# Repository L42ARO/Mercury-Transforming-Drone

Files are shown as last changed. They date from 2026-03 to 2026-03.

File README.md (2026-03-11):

# MERCURY - TRANSFORMING DRONE
<!-- Hardware / Platform -->







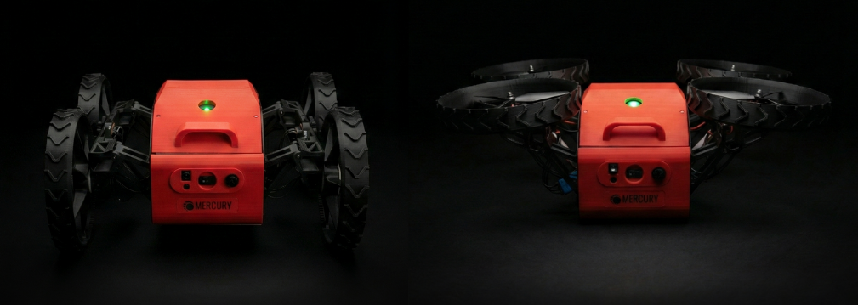
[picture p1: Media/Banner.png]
Mercury Banner





## Quick Index

- [Demo](#demo)
- [Features](#features)
- [Folder Structure](#folder-structure)
- [Software Setup](#software-setup)

## Demo

Mercury Demo (https://youtu.be/DZhdSxqXiKo)

## Features

<table width="100%">
  <tr>
    <td width="50%" align="center"><b>Inner Payload Bay (1 kg)</b></td>
    <td width="50%" align="center"><b>Simple Transformation Mechanism</b></td>
  </tr>
  <tr>
    <td width="50%" align="center">Inner Payload Bay</td>
    <td width="50%" align="center">Simple Transformation Mechanism</td>
  </tr>
</table>

<table width="100%">
  <tr>
    <td width="50%" align="center"><b>RGB + Depth + Thermal Cameras</b></td>
    <td width="50%" align="center"><b>Ardupilot + GPS</b></td>
  </tr>
  <tr>
    <td width="50%" align="center">RGB + Depth + Thermal Cameras</td>
    <td width="50%" align="center">Ardupilot + GPS</td>
  </tr>
</table>

<table width="100%">
  <tr>
    <td width="50%" align="center"><b>Wheel + Prop Guard</b></td>
    <td width="50%" align="center"><b>Mobile App</b></td>
  </tr>
  <tr>
    <td width="50%" align="center">Wheel + Prop Guard</td>
    <td width="50%" align="center">Mobile App</td>
  </tr>
</table>

## Folder Structure
- **STL Files:** all the required stl files for the drone assembly
- **Autonomy Software:** all the required software for the drone autonomy
- **PCB Files:** all the gerber files for the drone PCBs

## Software Setup

To use the software as it is, upload the Autonomy Software folder to a Raspberry Pi 5, using your preferred SCP method. For beginners we recommend [WinSCP](https://winscp.net/eng/download.php).

Inside the folder in the raspberry pi create a virtual environment and install the dependencies.

```bash
python3 -m venv venv
source venv/bin/activate
pip install -r requirements.txt
```

You must run both the Mavproxy Bridge to interface with the flight controller as well as the main software powering the rest of the robot. For that run in two separate temrinals the scripts:

```bash
start_mavproxy.sh
```
```bash
run.sh
```
In the terminal you should see the IP addres to be able to control the robot, if you're connected to the same network just copy paste that on your browser.

If you would like to be able to control it from different networks and at long distances we recommend you setup [Tailscale](https://tailscale.com/) on your devices.

For more convenience you can setup these scripts to run automatically on startup, and then use other scripts like `restarter.sh` or `killer.sh` to manage them.

## 🧑‍💻 Official Codebase Core Contributors and Maintainers

<table>
  <tr>
    <td align="center">
      <a href="https://x.com/L42ARO">
        
      </a>
      <br />
      <sub><b>Alvaro L</b></sub>
    </td>
    <td align="center">
      <a href="https://x.com/pericleshimself">
        
      </a>
      <br />
      <sub><b>Connor Raymer</b></sub>
    </td>
  </tr>
</table>



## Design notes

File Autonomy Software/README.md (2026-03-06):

# Mercury Delivery 🤖🧺🗺️

This repo is for TeleOperating delivery operations for Mercury

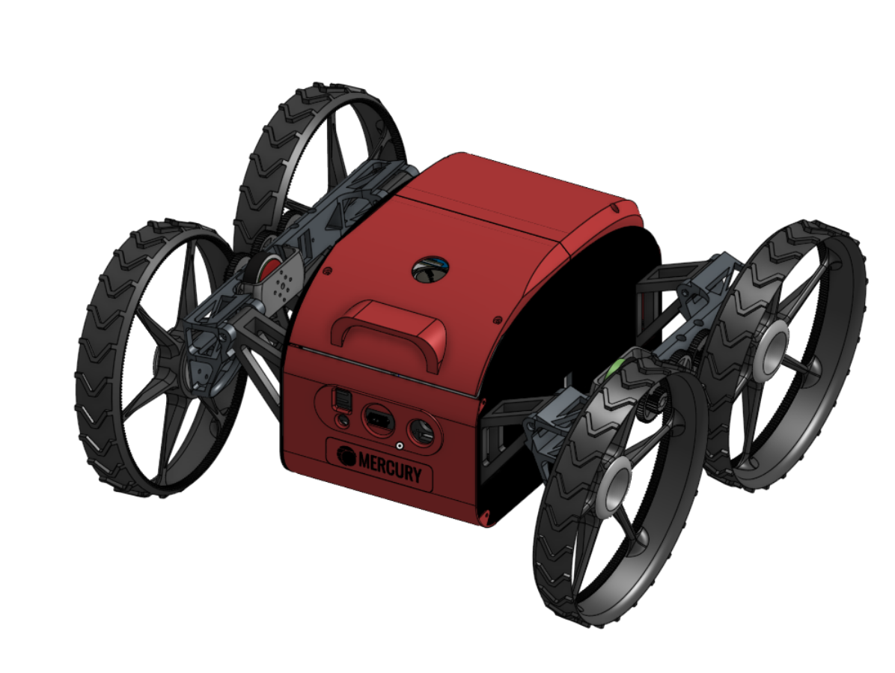
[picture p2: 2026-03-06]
Media/CAD.png

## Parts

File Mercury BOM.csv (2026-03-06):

Hardware | Link | Units
120N Linear Actuator 1.2" | https://a.co/d/f1gvmVA | 2
8 inch propellers | https://a.co/d/bCJhVNM | 4
BLDC Motor (A2812 2812 900KV) | https://a.co/d/0YZLBnR | 4
Raspberry Pi 5 | https://a.co/d/0e89eMiw | 1
Mobile Data Dongle | https://a.co/d/clkxkL8 | 1
Lipo Battery (3S 2200mah) | https://a.co/d/04b29lgE | 2
Screws (3mm x 10mm) | ACE Hardware | 10
Screws (3mm x 30 mm) | ACE Hardware | 20
Screws (3mm x 50 mm) | ACE Hardware | 10
CF 30 cm x 30 cm (for frame) | https://a.co/d/0dzbtn5p | 2
8 awg cable | https://www.amazon.com/dp/B07B8N6751?ref_=ppx_hzod_title_dt_b_fed_asin_title_0_1 | 1
T Plug Pairs | https://www.amazon.com/dp/B01C8NWJ78?ref_=ppx_hzod_title_dt_b_fed_asin_title_0_0 | 2
XT60 Male & Female | https://www.amazon.com/dp/B0CMM1BBDQ?ref_=ppx_hzod_title_dt_b_fed_asin_title_0_0 | 1
IMU (MPU 9250) | https://www.amazon.com/dp/B01I1J0Z7Y?ref_=ppx_hzod_title_dt_b_fed_asin_title_0_1 | 2
TOF Camera | https://www.amazon.com/dp/B0BRB12W7Y?ref_=ppx_hzod_title_dt_b_fed_asin_title_0_0 | 1
ESP32S3 | https://a.co/d/0fMawJYb | 1
USB Webcam | https://www.amazon.com/640x480-Building-Arduino-Raspberry-Robotic/dp/B0CT35HQJ5 | 1
Buck Converter | https://www.amazon.com/sspa/click | 3
Radiolink R8XM | https://www.amazon.com/dp/B0BCPDLWXZ?ref_=ppx_hzod_title_dt_b_fed_asin_title_0_0 | 1
DRV8871 H Bridge | https://a.co/d/iBVBORv | 2
Cube + Flight Controller | https://a.co/d/19FUWXO | 1
SEQURE 4in1 ESC 70A | https://a.co/d/5X12oWn | 1
Custom PCBS | EasyEDA | 3
BLDC Motor 140kv (for driving) | https://a.co/d/iKZayiN | 2
Optical Flow MTF-01 | https://www.ewingaerospace.com/products/ewing-aerospace-h7-flight-controller-ndaa-compliant-and-blueuas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 | 1
Thermal Camera | https://a.co/d/dZ3TK0W | 1
Bidirectional ESC 50A (for driving) | https://a.co/d/00C138fG | 2

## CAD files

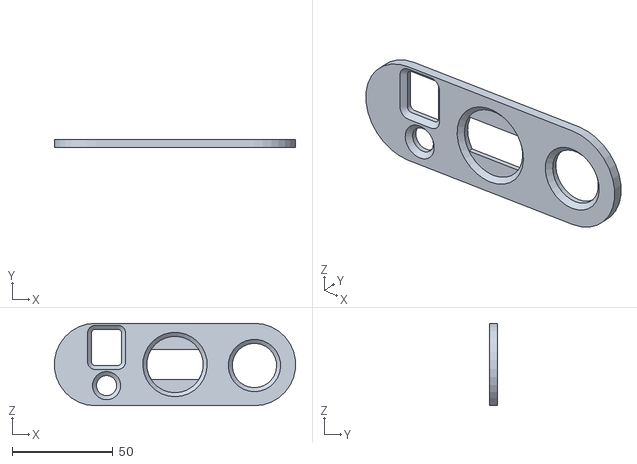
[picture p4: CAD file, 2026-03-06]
STL Files/Cover Out - Front Sensors.stl
119.8 x 4.00 x 41.0

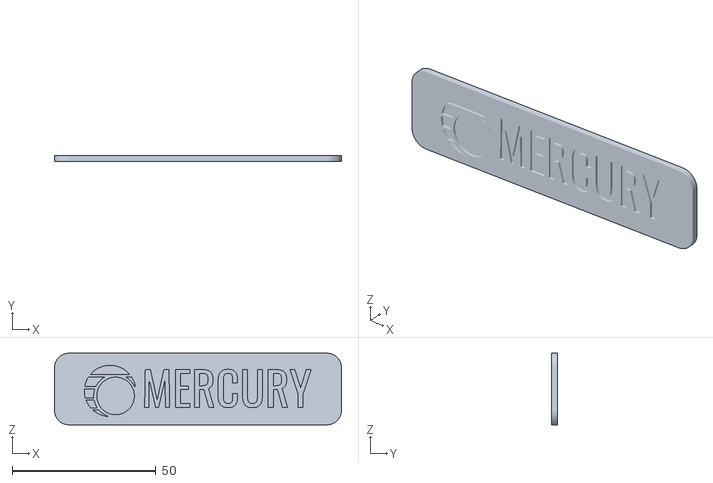
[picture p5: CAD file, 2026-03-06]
STL Files/Cover Out - Front Name.stl
100.0 x 2.00 x 25.0

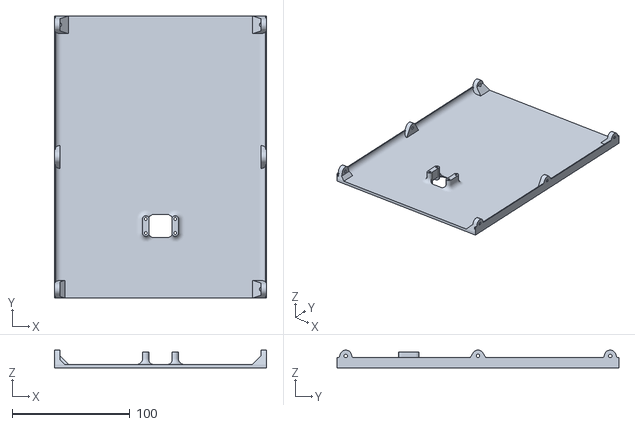
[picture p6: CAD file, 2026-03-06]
STL Files/Cover Out - Bottom.stl
180.8 x 240.0 x 15.1

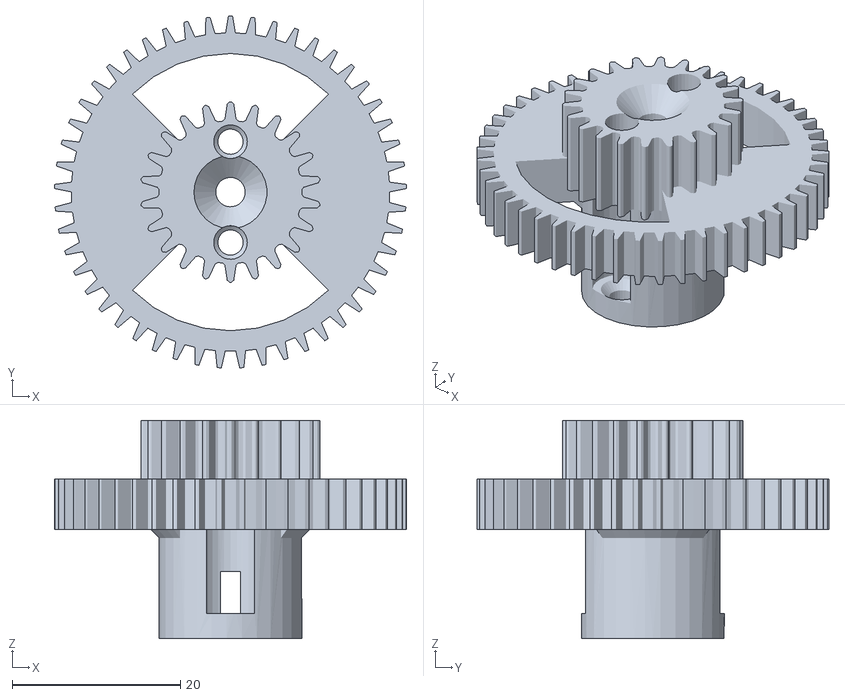
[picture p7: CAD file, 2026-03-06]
STL Files/Gear - Driving.stl
41.9 x 41.9 x 26.0

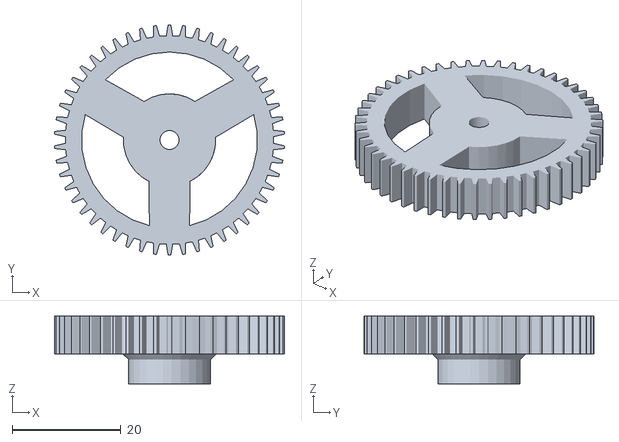
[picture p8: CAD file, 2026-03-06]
STL Files/Gear - Central.stl
42.3 x 42.4 x 12.5

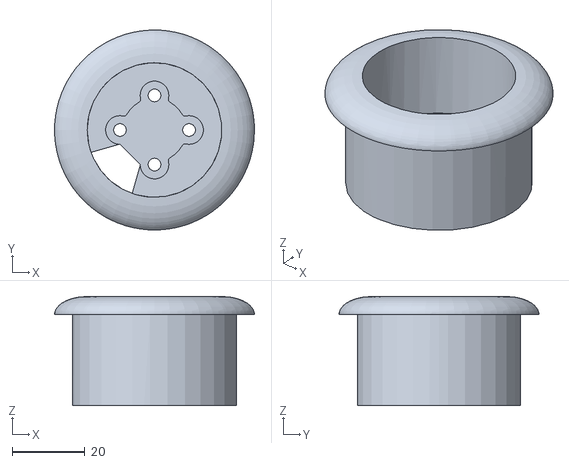
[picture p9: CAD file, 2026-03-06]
STL Files/Drone Motor Holder.stl
55.0 x 55.0 x 30.0

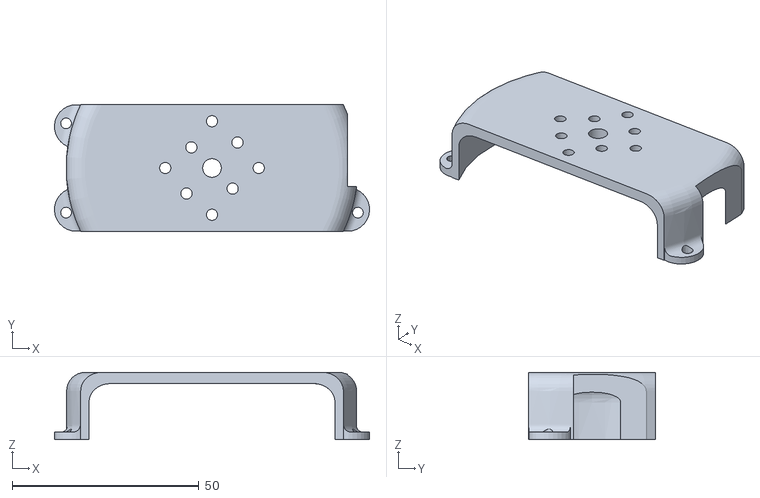
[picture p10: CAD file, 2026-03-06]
STL Files/BLDC Holder - Left.stl
84.2 x 33.9 x 18.0

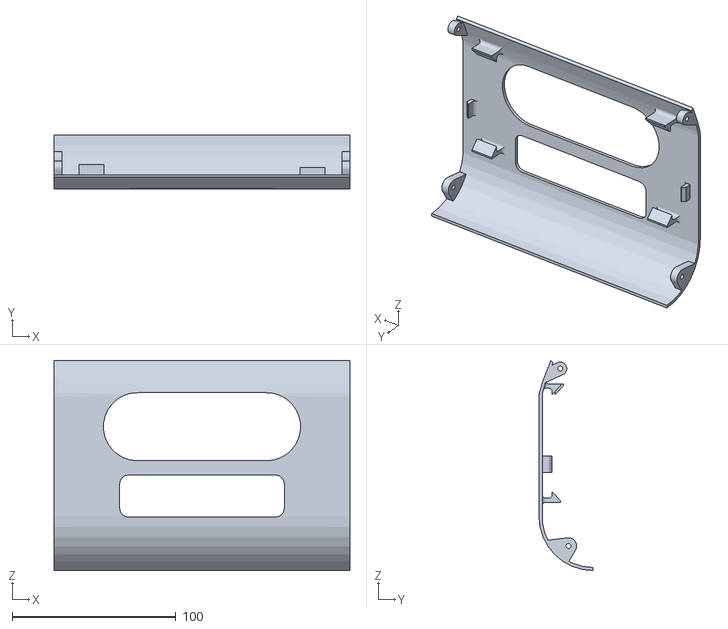
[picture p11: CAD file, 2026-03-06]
STL Files/Cover Out - Front.stl
180.8 x 33.0 x 128.3

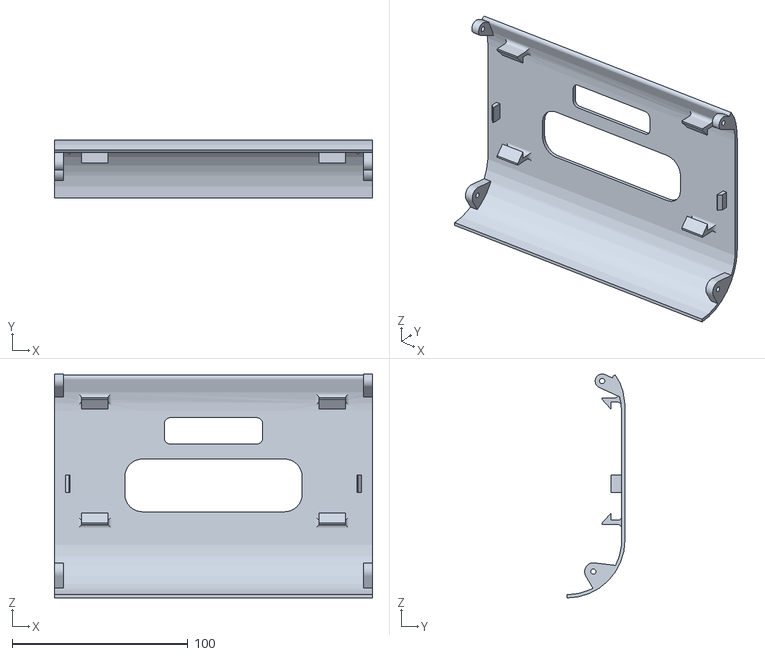
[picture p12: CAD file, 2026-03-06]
STL Files/Cover Out - Rear.stl
180.8 x 33.0 x 127.3

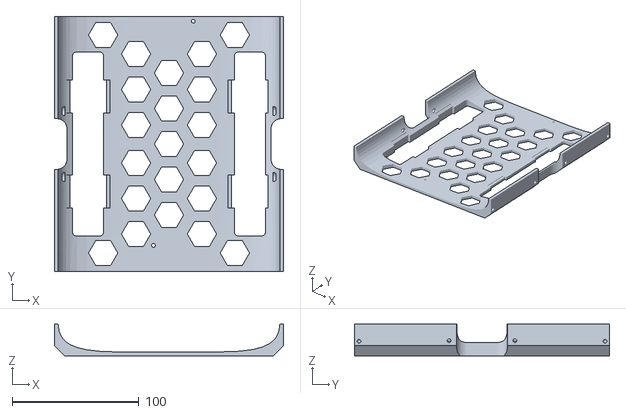
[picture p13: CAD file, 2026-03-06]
STL Files/CargoBay - Base.stl
180.8 x 201.2 x 25.0

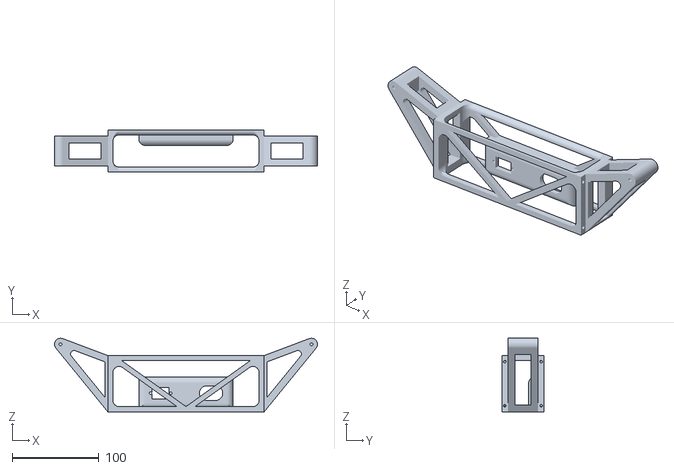
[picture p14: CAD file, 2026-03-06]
STL Files/ShoulderMount - Rear.stl
303.9 x 49.0 x 85.0

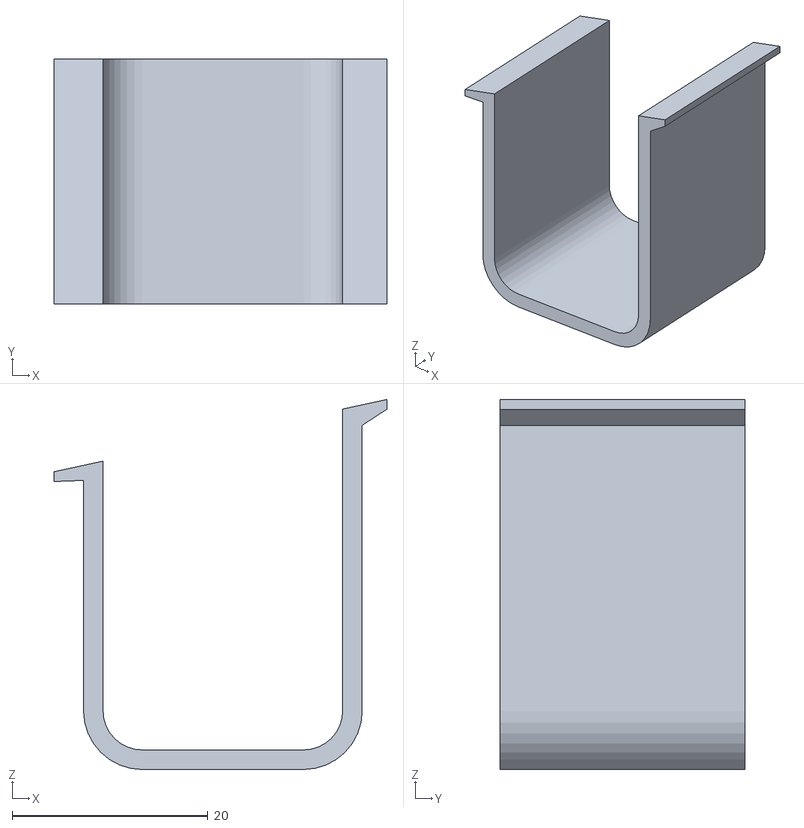
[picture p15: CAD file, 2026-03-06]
STL Files/CargoBay - Battery Holder 3.stl
34.0 x 25.0 x 37.8

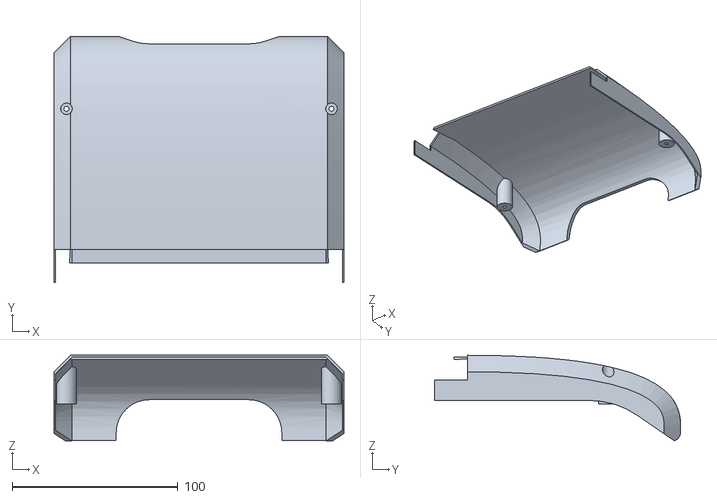
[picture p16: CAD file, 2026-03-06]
STL Files/Cover Out - Top Rear.stl
175.1 x 148.8 x 51.7

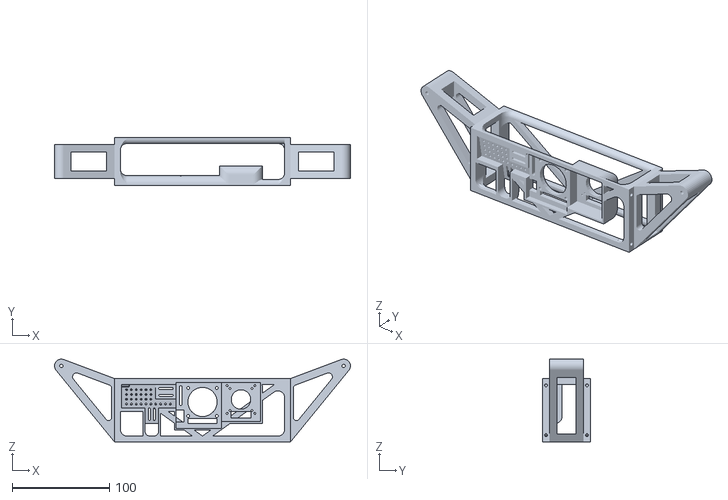
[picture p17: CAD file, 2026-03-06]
STL Files/ShoulderMount - Front.stl
303.9 x 49.0 x 85.0

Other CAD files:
STL Files/CargoBay - Battery Holder 4.stl
STL Files/BLDC Holder - Right.stl
STL Files/Cover Out - Top Front.stl
STL Files/Gear - Peripheral.stl
STL Files/CargoBay - Battery Holder 1.stl
STL Files/CargoBay - Battery Holder 2.stl
STL Files/CargoBay - Cover.stl
STL Files/Cover - Base.stl
STL Files/Linear Actuator Holder.stl

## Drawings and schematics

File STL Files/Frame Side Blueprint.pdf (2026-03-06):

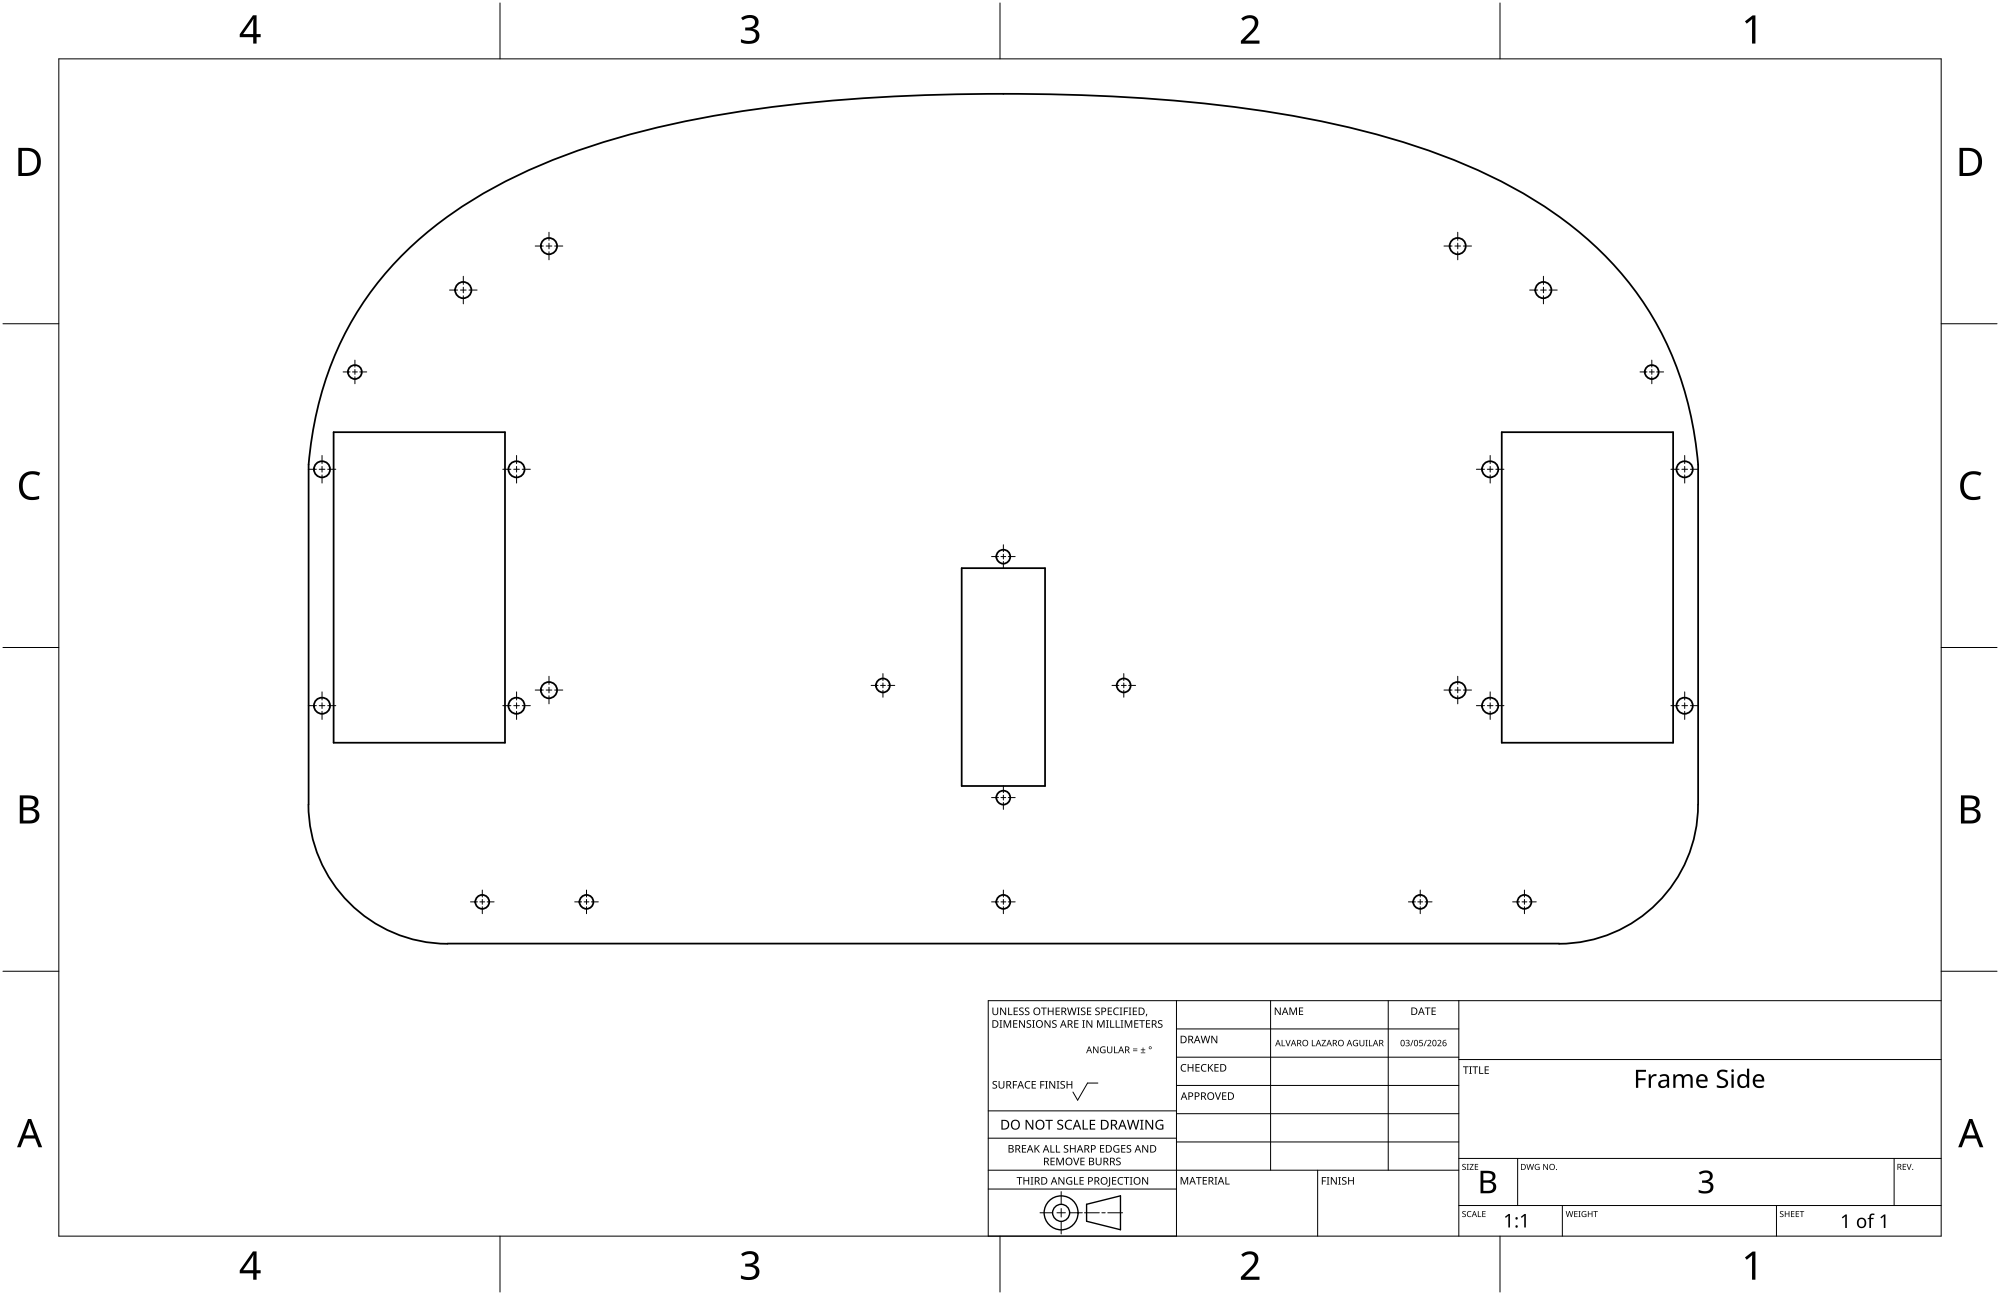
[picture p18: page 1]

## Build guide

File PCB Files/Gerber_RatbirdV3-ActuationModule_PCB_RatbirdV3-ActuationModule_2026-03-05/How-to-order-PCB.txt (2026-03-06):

How to Order PCB

Please refer to:
https://docs.easyeda.com/en/PCB/Order-PCB

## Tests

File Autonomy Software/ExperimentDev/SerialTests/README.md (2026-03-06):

# ACTUATION BOARD API

This document describes how to communicate with the ESP32-S3 controller from a Raspberry Pi using the **binary Serial 1 protocol** on `/dev/ttyAMA1`.
The API lets the Pi switch modes and drive the robot efficiently via framed byte packets (no strings).

---

## ⚙️ Serial setup

| Parameter | Value |
| --- | --- |
| Port | `/dev/ttyAMA1` |
| Baud rate | **115 200 bps** |
| Data format | 8 N 1 |
| TX / RX (Pi → ESP32) | ESP32 TX = D6, RX = D7 |
| Logic voltage | 3.3 V (direct UART) |

Python example:

```python
import serial
ser = serial.Serial('/dev/ttyAMA1', 115200, timeout=0.2)
```

---

## 🧱 Frame structure

Every packet (both directions) follows:

```
AA 55 <LEN> <CMD> <PAYLOAD…> <CHK>
```

| Field | Description |
| --- | --- |
| `AA 55` | Sync header |
| `<LEN>` | Payload + 1 byte for CMD |
| `<CMD>` | Command ID |
| `<PAYLOAD>` | Command-specific data |
| `<CHK>` | XOR of all bytes from `<LEN>` through last payload byte |

Example:
`AA 55 01 02 03` → `STOP_ALL` (len = 1, cmd = 0x02, chk = 0x03)

---

## 🧭 Command table (Pi → ESP32)

| CMD (HEX) | Name | Payload | Notes |
| --- | --- | --- | --- |
| `0x01` | **MODE_SET**  | `u8 mode` → 0 NONE  1 CAR  2 DRONE | Starts 10 s transform for CAR/DRONE |
| `0x02` | **STOP_ALL**  | – | Stops all motors immediately |
| `0x03` | **DRIVE_F** | `u8 pct (0-100)` | Forward (CAR mode only) |
| `0x04` | **DRIVE_B** | `u8 pct (0-100)` | Backward |
| `0x05` | **DRIVE_L** | `u8 pct (0-100)` | Left |
| `0x06` | **DRIVE_R** | `u8 pct (0-100)` | Right |
| `0x07` | **DRIVE_MIX** | `i8 left, i8 right` (-100..100) | Mixed differential drive |
| `0x08` | **TURNMODE**  | `u8 mode` → 0 SAME 1 TANK | Optional steering style |
| `0x09` | **DMAX_SET**  | `u16 delta_us (LE)` | Servo range 200-500 µs |
| `0x0A` | **STATUS_Q**  | – | Requests current status frame |

---

## 📡 Responses (ESP32 → Pi)

| Type | CMD ID | Payload | Meaning |
| --- | --- | --- | --- |
| **ACK** | `0x80` | `0x01` | OK |
| **ERR** | `0x81` | `u8 code` | 1 BadArg  2 BadMode  3 NotInCar  4 Unknown |
| **STATUS** | `0x82` | `mode u8 active u8 turn u8 dmax u16 reserved u8` | 6-byte status payload |

All responses use the same `AA 55 <LEN> <CMD> … <CHK>` format.

---

## ⏱ Timing guidelines

| Command type | Recommended wait before next |
| --- | --- |
| `MODE_SET` (CAR/DRONE) | ~ 10 s  (physical transform duration) |
| Drive commands (`F/B/L/R/MIX`) | Wait until motion finishes (typically 2-3 s) |
| `STOP_ALL` / `STATUS_Q` | 0.1 s |

---

## 🧪 Example Python usage

```python
import serial, struct, time
ser = serial.Serial('/dev/ttyAMA1', 115200, timeout=0.2)

def frame(cmd, payload=b''):
    body = bytes([len(payload)+1, cmd]) + payload
    chk = 0
    for x in body: chk ^= x
    return b'\xAA\x55' + body + bytes([chk])

def send(cmd, payload=b'', wait=0.0, label=''):
    print(f"➡️  {label or hex(cmd)}")
    ser.write(frame(cmd, payload))
    resp = ser.read(64)
    if resp: print("⬅️ ", resp.hex(' '))
    else:    print("⬅️  (no response)")
    time.sleep(wait)

# --- sample sequence ---
send(0x01, bytes([1]), 0.1, "MODE CAR")
print("waiting 10 s for transformation…")
time.sleep(10)

send(0x03, bytes([50]), 0.1, "DRIVE FORWARD 50%")
time.sleep(3)
send(0x02, b'', 0.1, "STOP_ALL")

payload = struct.pack('bb', -30, 60)
send(0x07, payload, 0.1, "DRIVE_MIX (-30,+60)")
time.sleep(2)
send(0x02, b'', 0.1, "STOP_ALL")

send(0x01, bytes([2]), 0.1, "MODE DRONE")
time.sleep(10)
send(0x0A, b'', 0.2, "STATUS_Q")
```

---

## 🪪 Quick reference (hex examples)

| Action | Frame |
| --- | --- |
| MODE CAR | `AA 55 02 01 01 03` |
| STOP_ALL | `AA 55 01 02 03` |
| DRIVE F 50% | `AA 55 02 03 32 31` |
| DRIVE MIX (-30,+60) | `AA 55 03 07 E2 3C 18` |
| STATUS_Q | `AA 55 01 0A 0B` |

---

## 🧰 Debugging tips

* Use `minicom` or `screen /dev/ttyAMA1 115200` to verify bytes.
* Every valid frame begins with `AA 55`.
* `0x80` ACK → success; `0x81` ERR → check payload for error code.
* If you get no response, ensure grounds are common and TX/RX aren’t swapped.

---

**Author:** Mercurius Robotics
**Purpose:** Efficient serial bridge for Pi ↔ ESP32 differential-drive controller.

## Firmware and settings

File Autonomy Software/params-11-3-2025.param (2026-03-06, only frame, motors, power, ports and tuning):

ATC_ANG_LIM_TC,1
ATC_ANG_PIT_P,4.5
ATC_ANG_RLL_P,4.5
ATC_ANG_YAW_P,4.5
ATC_ANGLE_BOOST,1
ATC_RAT_PIT_D,0.0036
ATC_RAT_PIT_D_FF,0
ATC_RAT_PIT_FF,0
ATC_RAT_PIT_FLTD,20
ATC_RAT_PIT_FLTE,0
ATC_RAT_PIT_FLTT,20
ATC_RAT_PIT_I,0.24
ATC_RAT_PIT_IMAX,0.5
ATC_RAT_PIT_P,0.22
ATC_RAT_PIT_PDMX,0
ATC_RAT_PIT_SMAX,0
ATC_RAT_RLL_D,0.0036
ATC_RAT_RLL_D_FF,0
ATC_RAT_RLL_FF,0
ATC_RAT_RLL_FLTD,20
ATC_RAT_RLL_FLTE,0
ATC_RAT_RLL_FLTT,20
ATC_RAT_RLL_I,0.24
ATC_RAT_RLL_IMAX,0.5
ATC_RAT_RLL_P,0.22
ATC_RAT_RLL_PDMX,0
ATC_RAT_RLL_SMAX,0
ATC_RAT_YAW_D,0
ATC_RAT_YAW_D_FF,0
ATC_RAT_YAW_FF,0
ATC_RAT_YAW_FLTD,20
ATC_RAT_YAW_FLTE,10
ATC_RAT_YAW_FLTT,10
ATC_RAT_YAW_I,0.24
ATC_RAT_YAW_IMAX,0.5
ATC_RAT_YAW_P,0.22
ATC_RAT_YAW_PDMX,0
ATC_RAT_YAW_SMAX,0
ATC_RATE_FF_ENAB,1
ATC_RATE_P_MAX,0
ATC_RATE_R_MAX,0
ATC_RATE_Y_MAX,0
BATT_AMP_OFFSET,0
BATT_AMP_PERVLT,52
BATT_ARM_MAH,0
BATT_ARM_VOLT,0
BATT_CAPACITY,2200
BATT_CRT_MAH,0
BATT_CRT_VOLT,0
BATT_CURR_PIN,11
BATT_FS_CRT_ACT,0
BATT_FS_LOW_ACT,0
BATT_FS_VOLTSRC,0
BATT_LOW_MAH,0
BATT_LOW_TIMER,10
BATT_LOW_VOLT,10.5
BATT_MONITOR,4
BATT_OPTIONS,0
BATT_SERIAL_NUM,-1
BATT_VLT_OFFSET,0
BATT_VOLT_MULT,11.2
BATT_VOLT_PIN,10
BATT2_MONITOR,0
BATT3_MONITOR,0
BATT4_MONITOR,0
BATT5_MONITOR,0
BATT6_MONITOR,0
BATT7_MONITOR,0
BATT8_MONITOR,0
BATT9_MONITOR,0
FLTMODE_CH,5
FLTMODE_GCSBLOCK,0
FLTMODE1,2
FLTMODE2,2
FLTMODE3,9
FLTMODE4,16
FLTMODE5,6
FLTMODE6,9
FRAME_CLASS,1
FRAME_TYPE,1
INS_GYRO_FILTER,20
INS_HNTCH_ENABLE,0
MOT_BAT_CURR_MAX,35
MOT_BAT_CURR_TC,5
MOT_BAT_IDX,0
MOT_BAT_VOLT_MAX,0
MOT_BAT_VOLT_MIN,0
MOT_BOOST_SCALE,0
MOT_HOVER_LEARN,2
MOT_OPTIONS,0
MOT_PWM_MAX,2000
MOT_PWM_MIN,1000
MOT_PWM_TYPE,6
MOT_SAFE_DISARM,0
MOT_SAFE_TIME,1
MOT_SLEW_DN_TIME,0
MOT_SLEW_UP_TIME,0
MOT_SPIN_ARM,0.1
MOT_SPIN_MAX,0.95
MOT_SPIN_MIN,0.15
MOT_SPOOL_TIM_DN,0
MOT_SPOOL_TIME,0.5
MOT_THST_EXPO,0.65
MOT_THST_HOVER,0.668889
MOT_YAW_HEADROOM,200
SERIAL0_BAUD,115
SERIAL0_PROTOCOL,2
SERIAL1_BAUD,115
SERIAL1_OPTIONS,8
SERIAL1_PROTOCOL,2
SERIAL2_BAUD,9
SERIAL2_OPTIONS,0
SERIAL2_PROTOCOL,23
SERIAL3_BAUD,115
SERIAL3_OPTIONS,1184
SERIAL3_PROTOCOL,1
SERIAL4_BAUD,57
SERIAL4_OPTIONS,0
SERIAL4_PROTOCOL,2
SERIAL5_BAUD,115
SERIAL5_OPTIONS,0
SERIAL5_PROTOCOL,16
SERIAL6_BAUD,9
SERIAL6_OPTIONS,0
SERIAL6_PROTOCOL,5
SERVO1_FUNCTION,34
SERVO1_MAX,2000
SERVO1_MIN,1000
SERVO1_REVERSED,0
SERVO1_TRIM,1000
SERVO2_FUNCTION,35
SERVO2_MAX,2000
SERVO2_MIN,1000
SERVO2_REVERSED,0
SERVO2_TRIM,1000
SERVO3_FUNCTION,36
SERVO3_MAX,2000
SERVO3_MIN,1000
SERVO3_REVERSED,0
SERVO3_TRIM,1000
SERVO4_FUNCTION,33
SERVO4_MAX,2000
SERVO4_MIN,1000
SERVO4_REVERSED,0
SERVO4_TRIM,1000
SERVO5_FUNCTION,0
SERVO5_MAX,1900
SERVO5_MIN,1100
SERVO5_REVERSED,0
SERVO5_TRIM,1500
SERVO6_FUNCTION,0
SERVO6_MAX,1900
SERVO6_MIN,1100
SERVO6_REVERSED,0
SERVO6_TRIM,1500
SERVO7_FUNCTION,0
SERVO7_MAX,1900
SERVO7_MIN,1100
SERVO7_REVERSED,0
SERVO7_TRIM,1500
SERVO8_FUNCTION,0
SERVO8_MAX,1900
SERVO8_MIN,1100
SERVO8_REVERSED,0
SERVO8_TRIM,1500
SERVO9_FUNCTION,120
SERVO9_MAX,1900
SERVO9_MIN,1100
SERVO9_REVERSED,0
SERVO9_TRIM,1500

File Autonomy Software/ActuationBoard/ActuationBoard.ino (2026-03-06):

// ================== Pins: TRANSFORMATION (H-bridge) ==================
// ================== Pins: TRANSFORMATION (H-bridge) ==================
#define ENA D10     // <— moved off D0 to free D0
#define IN1 D1
#define IN2 D2
#define IN3 D3
#define ENB D10     // (if ENA/ENB tie together in your board, keep both on D10 or split as needed)
#define IN4 39

// New: lock servo pin
#define LOCK_SERVO_PIN D0   // XIAO ESP32S3 D0 = GPIO1 (PWM-capable)


// ================== Pins: DRIVE SERVOS (DIFFERENTIAL) ==================
#define SERVO_LEFT_PIN  D9   // LEFT drive servo
#define SERVO_RIGHT_PIN D8   // RIGHT drive servo

// ================== LED ==================
#ifdef LED_BUILTIN
  #define LED_PIN LED_BUILTIN
#else
  #define LED_PIN 2
#endif
#define LED_ACTIVE_HIGH false

// ================== Timing ==================
const uint32_t CAR_RUN_MS   = 10000; // 10 s transform after MODE CAR
const uint32_t DRONE_RUN_MS = 10000; // 10 s transform after MODE DRONE
const uint32_t LED_DRONE_INTERVAL = 300; // blink while DRONE active

// ================== Serial1 (Raspberry Pi link) ==================
#define RX_PIN D7
#define TX_PIN D6
#define BAUD   115200

// ================== Includes ==================
#include "ModeController.h"
#include "DriveController.h"
#include "Serial1API.h"
#include "LockController.h"


// ================== Human CLI over USB Serial ==================
static String inBuf;
static inline int clampi(int v, int lo, int hi){ return v<lo?lo:(v>hi?hi:v); }

static void printHelp(){
  Serial.println(
    "\nCommands:\n"
    "  MODE CAR|DRONE|NONE     -> CAR/DRONE: run transform 10s, stop; mode is retained\n"
    "  S                        -> stop all motors (transform + servos), mode unchanged\n"
    "  F <pct>                  -> forward  [CAR only] (mapped to L-, R+)\n"
    "  B <pct>                  -> backward [CAR only] (mapped to L+, R-)\n"
    "  L <pct> / R <pct>        -> LEFT/RIGHT; SAME: L=(-,-) R=(+,+) | TANK: L=(-,+) R=(+,-)\n"
    "  TURNMODE SAME|TANK       -> SAME or TANK turning behavior\n"
    "  DMAX <us>                -> servoMaxDeltaUs (200..500)\n"
    "  M <L%> <R%>              -> mixed (-100..100) [CAR only]\n"
    "  LOCK [ms]                -> move to center and hold (default 1000 ms)\n"
    "  UNLOCK                   -> sweep 0→180→0\n"
    "  ? / HELP                 -> this help\n"
  );
}

static void handleLine(String s){
  s.trim(); if (!s.length()) return;
  s.replace("\t"," "); while (s.indexOf("  ") >= 0) s.replace("  ", " ");
  int sp = s.indexOf(' ');
  String cmd  = (sp>=0)? s.substring(0,sp) : s;
  String rest = (sp>=0)? s.substring(sp+1): "";
  cmd.toUpperCase();

  if (cmd=="?" || cmd=="HELP"){ printHelp(); return; }

  if (cmd=="MODE"){
    String m = rest; m.toUpperCase();
    if (m=="CAR"){   Mode_enter(MODE_CAR);   return; }
    if (m=="DRONE"){ Mode_enter(MODE_DRONE); return; }
    if (m=="NONE"){  Mode_setNone(); return; }
    Serial.println("ERR: MODE must be CAR, DRONE, or NONE");
    return;
  }

  if (cmd=="S"){
    Mode_stopAll();
    Drive_stop();
    Serial.println("OK: stop");
    return;
  }

  if (cmd=="TURNMODE"){
    String m = rest; m.toUpperCase();
    if (m=="SAME"){ Drive_setTurnMode(TURN_SAME_SIGN); Serial.println("OK: TURNMODE=SAME"); return; }
    if (m=="TANK"){ Drive_setTurnMode(TURN_TANK);      Serial.println("OK: TURNMODE=TANK");  return; }
    Serial.println("ERR: TURNMODE must be SAME or TANK");
    return;
  }

  if (cmd=="DMAX"){
    int v = rest.toInt(); v = clampi(v, 200, 500);
    Drive_setMaxDeltaUs(v);
    Serial.printf("OK: servoMaxDeltaUs=%d\n", v);
    return;
  }

  // ===== Drive (CAR mode only) =====
  if (cmd=="M" || cmd=="F" || cmd=="B" || cmd=="L" || cmd=="R"){
    if (Mode_get() != MODE_CAR && false){ Serial.println("ERR: Drive only in CAR mode. Use 'MODE CAR'."); return; }
    Mode_cancelRun(); // cancel any 10s transform run when taking manual drive

    if (cmd=="M"){
      int sp2 = rest.indexOf(' ');
      if (sp2 < 0){ Serial.println("ERR: M needs two values"); return; }
      int lp = rest.substring(0, sp2).toInt();
      int rp = rest.substring(sp2 + 1).toInt();
      Drive_percent(lp, rp);
      Serial.printf("OK: M L=%d%% R=%d%%\n", lp, rp);
      return;
    }

    int pct = clampi(rest.toInt(), 0, 100);
    if (cmd=="F"){ Drive_forward(pct);   Serial.printf("OK: F %d%%\n", pct); return; }
    if (cmd=="B"){ Drive_backward(pct);  Serial.printf("OK: B %d%%\n", pct); return; }
    if (cmd=="L"){ Drive_left(pct);      Serial.printf("OK: L %d%%\n", pct); return; }
    if (cmd=="R"){ Drive_right(pct);     Serial.printf("OK: R %d%%\n", pct); return; }
  }

    if (cmd=="LOCK"){
    int hold = rest.length() ? rest.toInt() : 1000;
    if (hold <= 0) hold = 1000;
    Lock_now((uint16_t)hold);
    Serial.printf("OK: LOCK %dms\n", hold);
    return;
  }

  if (cmd=="UNLOCK"){
    Unlock_now();
    Serial.println("OK: UNLOCK sweep");
    return;
  }


  Serial.println("ERR: unknown command. Type '?' for help.");
}

// ================== Arduino ==================
void setup(){
  Serial.begin(115200);

  // Binary API for Raspberry Pi on Serial1
  S1_Init(BAUD, RX_PIN, TX_PIN);

  // Init controllers
  Mode_init(ENA, ENB, IN1, IN2, IN3, IN4,
            LED_PIN, LED_ACTIVE_HIGH,
            CAR_RUN_MS, DRONE_RUN_MS, LED_DRONE_INTERVAL);

  Drive_init(SERVO_LEFT_PIN, SERVO_RIGHT_PIN, 1000, 2000, 1500);

  // NEW: Lock controller (50 Hz, 1000–2000us)
  Lock_init(LOCK_SERVO_PIN, 1000, 2000, 50);

  // If your Serial1API supports registering a handler, do it here:
  // S1_RegisterHandler(Lock_S1_Handle);

  Serial.println("Ready. USB Serial = human CLI ('?'), Serial1 = Pi binary API.");
  Serial.println("Start with 'MODE CAR' or 'MODE DRONE'.");
}

void loop(){
  // Human CLI over USB
  while (Serial.available()){
    char c = (char)Serial.read();
    if (c == '\r') continue;
    if (c == '\n'){ handleLine(inBuf); inBuf = ""; }
    else {
      inBuf += c;
      if (inBuf.length() > 160) inBuf = "";
    }
  }

  // Background engines
  Mode_update();  // handles 10s timeout & LED blink
  S1_Update();    // parses/dispatches Raspberry Pi frames
}

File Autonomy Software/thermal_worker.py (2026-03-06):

import cv2
import sys
import time
import numpy as np
import os
import struct
import signal

# --- CONFIG ---
SENSOR_WIDTH = 256
SENSOR_HEIGHT = 192
OUTPUT_WIDTH = 768
OUTPUT_HEIGHT = 576
ALPHA = 1.0       # Contrast
BLUR_RADIUS = 2  # Blur factor

# Force standard V4L2
os.environ["OPENCV_VIDEOIO_PRIORITY_MSMF"] = "0"

# Global flag for clean exit
RUNNING = True

def handle_signal(signum, frame):
    """Catch kill signals to ensure camera release"""
    global RUNNING
    RUNNING = False

# Register signals (SIGINT = Ctrl+C, SIGTERM = kill command)
signal.signal(signal.SIGINT, handle_signal)
signal.signal(signal.SIGTERM, handle_signal)

def main():
    global RUNNING
    
    # Debug message to stderr (so it shows in main console)
    sys.stderr.write("[thermal_worker] Process started. Searching for camera...\n")
    sys.stderr.flush()
    
    # 1. Open Camera (Hardcoded index 4)
    cap = None
    for i in range(5):
        if not RUNNING: return
        # Try index 4 first
        cap = cv2.VideoCapture(4, cv2.CAP_V4L2)
        if cap.isOpened():
            sys.stderr.write("[thermal_worker] Locked on /dev/video4\n")
            break
        # Fallback to 5 immediately if 4 failed
        cap = cv2.VideoCapture(5, cv2.CAP_V4L2)
        if cap.isOpened():
            sys.stderr.write("[thermal_worker] Locked on /dev/video5\n")
            break
        time.sleep(1.0)
    
    if not cap or not cap.isOpened():
        sys.stderr.write("[thermal_worker] Critical: Failed to open device 4 or 5\n")
        return

    # 2. Configure Raw Mode (CRITICAL)
    cap.set(cv2.CAP_PROP_CONVERT_RGB, 0.0)
    
    # 3. Stream Loop
    while RUNNING:
        try:
            ret, raw_frame = cap.read()
            if not ret or raw_frame is None:
                time.sleep(0.01)
                continue

            # --- Les Wright Processing Logic ---
            h, w = raw_frame.shape[:2]
            
            # Handle flat buffers (driver quirk)
            if h == 1 and w > 1000:
                raw_frame = raw_frame.reshape(384, 256, 2)
                h, w = 384, 256

            if h == 384:
                # Split (Top=Video, Bottom=Temp)
                imdata, thdata = np.array_split(raw_frame, 2)
                
                # Convert YUYV -> BGR (Fixes "Stretched Purple")
                bgr = cv2.cvtColor(imdata, cv2.COLOR_YUV2BGR_YUYV)
                
                # Process
                if ALPHA != 1.0:
                    bgr = cv2.convertScaleAbs(bgr, alpha=ALPHA)
                
                bgr = cv2.resize(bgr, (OUTPUT_WIDTH, OUTPUT_HEIGHT), interpolation=cv2.INTER_CUBIC)
                
                if BLUR_RADIUS > 0:
                    bgr = cv2.blur(bgr, (BLUR_RADIUS, BLUR_RADIUS))

                # Color map
                heatmap = cv2.applyColorMap(bgr, cv2.COLORMAP_PLASMA)
                
                # --- ROTATION FIX ---
                # Rotate 90 degrees Counter-Clockwise
                heatmap = cv2.rotate(heatmap, cv2.ROTATE_90_COUNTERCLOCKWISE)
                # --------------------
                
                # Encode to JPEG
                ok, buf = cv2.imencode(".jpg", heatmap, [cv2.IMWRITE_JPEG_QUALITY, 80])
                if ok:
                    data = buf.tobytes()
                    # Write Packet: [FRAME] [LEN] [DATA]
                    sys.stdout.buffer.write(b'FRAME')
                    sys.stdout.buffer.write(struct.pack('<L', len(data)))
                    sys.stdout.buffer.write(data)
                    sys.stdout.buffer.flush()
        except BrokenPipeError:
            # Parent process died, exit immediately
            RUNNING = False
        except Exception:
            pass

    # Cleanup
    if cap: 
        cap.release()

if __name__ == "__main__":
    main()

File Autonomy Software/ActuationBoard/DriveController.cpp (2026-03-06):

#include "DriveController.h"
#include <ESP32Servo.h>
#include <Arduino.h>

// ====== ESC control (for BLDC) ======
static Servo s_escL, s_escR;

static int  s_pinL, s_pinR;
static int  s_usMin      = 1000;    // 1.000 ms
static int  s_usMax      = 2000;    // 2.000 ms
static int  s_usNeutral  = 1500;    // 1.500 ms
static int  s_usDelta    = 400;     // ±400us around neutral for 100%
static int  s_deadbandUs = 40;      // snap to neutral if within this band
static bool s_invertL    = true;    // keep your polarity choices
static bool s_invertR    = false;
static bool s_reverseEnabled = true;

static TurnStyle s_turnMode = TURN_SAME_SIGN;

// ====== Behavior tuning (edit to taste) ======
static int  s_brakePct          = 25;    // % magnitude for the brake pulse
static int  s_brakeMs           = 350;   // duration of the brake pulse
static int  s_startBoostPctMin  = 40;    // if target is below this, temporarily boost to this
static int  s_startBoostMs      = 180;   // duration of startup boost
static int  s_minMovePct        = 8;     // below this we consider "effectively zero"
static int  s_slewPctPerSec     = 250;   // ramp limit (percent per second)
static int  s_updatePeriodMs    = 10;    // control task period

// ====== Internal control task ======
static TaskHandle_t s_driveTask = nullptr;

// ====== Helpers ======
static inline int clampi(int v, int lo, int hi){ return v<lo?lo:(v>hi?hi:v); }
static inline int sgn(int v){ return (v>0) - (v<0); }

static int pctToEscUs(int pct, bool invert){
  pct = clampi(pct, -100, 100);
  if (invert) pct = -pct;
  if (!s_reverseEnabled) pct = clampi(pct, 0, 100);
  int us = s_usNeutral + (pct * s_usDelta) / 100;
  if (abs(us - s_usNeutral) <= s_deadbandUs) us = s_usNeutral;
  if (us < s_usMin) us = s_usMin;
  if (us > s_usMax) us = s_usMax;
  return us;
}

static void writeBothUs(int l_us, int r_us){
  s_escL.writeMicroseconds(l_us);
  s_escR.writeMicroseconds(r_us);
}

static void escArm_sequence_robust(){
  // Try NEUTRAL-first (many car ESCs):
  writeBothUs(s_usNeutral, s_usNeutral);
  delay(1200);
  // brief min, then neutral again (some ESCs need to "see" min edge)
  writeBothUs(s_usMin, s_usMin);
  delay(300);
  writeBothUs(s_usNeutral, s_usNeutral);
  delay(500);

  // Show min a second time for ESCs expecting min-first
  writeBothUs(s_usMin, s_usMin);
  delay(700);
  writeBothUs(s_usNeutral, s_usNeutral);
  delay(500);
}

// ====== Per-motor state machine ======
enum Phase : uint8_t {
  PHASE_IDLE = 0,      // not moving (or holding neutral)
  PHASE_START_BOOST,   // short boost to overcome static friction
  PHASE_RUNNING,       // tracking target with slew limiting
  PHASE_BRAKE          // brief opposite command to counter inertia
};

struct MotorCtl {
  volatile int targetPct;     // user-requested target (-100..100)
  volatile int appliedPct;    // what we are currently outputting (-100..100)
  volatile Phase phase;       // current phase
  volatile uint32_t untilMs;  // phase end time (millis)
  int lastNonZeroSign;        // sign of last non-zero applied (-1/0/1)
};

static MotorCtl s_L{0,0,PHASE_IDLE,0,0};
static MotorCtl s_R{0,0,PHASE_IDLE,0,0};

// forward decl
static void setTargets(int lpct, int rpct);
static void requestForMotor(MotorCtl& m, int newTarget);
static void serviceOne(MotorCtl& m);
static void driveTaskFn(void*);

// ====== Public API ======
void Drive_init(int pinLeft, int pinRight, int usMin, int usMax, int usCenter){
  s_pinL = pinLeft; s_pinR = pinRight;
  s_usMin = usMin; s_usMax = usMax; s_usNeutral = usCenter;

  // MATCH your previous Python (PCA9685 @ 60 Hz)
  s_escL.setPeriodHertz(60);
  s_escR.setPeriodHertz(60);
  s_escL.attach(s_pinL, s_usMin, s_usMax);
  s_escR.attach(s_pinR, s_usMin, s_usMax);

  escArm_sequence_robust();

  // Reset states
  s_L = MotorCtl{0,0,PHASE_IDLE,0,0};
  s_R = MotorCtl{0,0,PHASE_IDLE,0,0};

  // Park at neutral
  writeBothUs(s_usNeutral, s_usNeutral);

  // Launch control task (pin to core 0 so you keep loop() on core 1)
  xTaskCreatePinnedToCore(driveTaskFn, "driveCtl", 4096, nullptr, 1, &s_driveTask, 0);
}

void Drive_stop(){
  setTargets(0, 0);
}

void Drive_setTurnMode(TurnStyle mode){
  s_turnMode = mode;
}

void Drive_setMaxDeltaUs(int deltaUs){
  s_usDelta = clampi(deltaUs, 200, 500);
}

void Drive_setReverseEnabled(bool enabled){
  s_reverseEnabled = enabled;
}

void Drive_percent(int leftPct, int rightPct){
  setTargets(leftPct, rightPct);
}

// ================== High-level mappings (kept) ==================
void Drive_forward(int pct){
  pct = clampi(pct, 0, 100);
  // your wiring maps forward to L=+pct, R=-pct
  setTargets(pct, -pct);
}

void Drive_backward(int pct){
  pct = clampi(pct, 0, 100);
  if (!s_reverseEnabled){ Drive_stop(); return; }
  setTargets(-pct, +pct);
}

void Drive_left(int pct){
  pct = clampi(pct, 0, 100);
  if (s_turnMode == TURN_SAME_SIGN) setTargets(-pct, -pct);
  else                              setTargets(-pct, +pct); // tank
}

void Drive_right(int pct){
  pct = clampi(pct, 0, 100);
  if (s_turnMode == TURN_SAME_SIGN) setTargets(+pct, +pct);
  else                              setTargets(+pct, -pct); // tank
}

// ====== Internals ======

static void requestForMotor(MotorCtl& m, int newTarget){
  newTarget = clampi(newTarget, -100, 100);

  // Read volatile fields once
  const int oldTarget = m.targetPct;
  const int oldApplied = m.appliedPct;
  const int oldSign = sgn(oldApplied);
  const int newSign = sgn(newTarget);

  m.targetPct = newTarget;
  const uint32_t now = millis();

  // Moving -> Stop : apply a brief opposite brake
  if (oldSign != 0 && newTarget == 0) {
    const int brakeCmd = -oldSign * s_brakePct; // opposite dir
    m.phase   = PHASE_BRAKE;
    m.untilMs = now + s_brakeMs;
    m.appliedPct = brakeCmd; // immediate feel
    return;
  }

  // Stop -> small move : startup boost
  if (oldSign == 0 && newSign != 0 && abs(newTarget) < s_startBoostPctMin) {
    const int boost = sgn(newTarget) * s_startBoostPctMin;
    m.phase   = PHASE_START_BOOST;
    m.untilMs = now + s_startBoostMs;
    m.appliedPct = boost;
    return;
  }

  // Direction flip while moving : short brake first
  if (oldSign != 0 && newSign != 0 && oldSign != newSign) {
    const int brakeCmd = -oldSign * s_brakePct;
    m.phase   = PHASE_BRAKE;
    m.untilMs = now + (s_brakeMs / 2);
    m.appliedPct = brakeCmd;
    return;
  }

  // Otherwise: running (or idle if target zero)
  m.phase = (newSign == 0 ? PHASE_IDLE : PHASE_RUNNING);
  // actual ramping happens in serviceOne()
}

static void setTargets(int lpct, int rpct){
  requestForMotor(s_L, lpct);
  requestForMotor(s_R, rpct);
}
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
